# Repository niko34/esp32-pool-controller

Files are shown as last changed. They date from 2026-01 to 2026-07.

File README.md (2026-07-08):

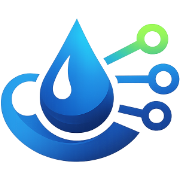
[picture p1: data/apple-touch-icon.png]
<h1> ESP32 Pool Controller</h1>

Disclaimer : projet en cours de construction.

Contrôleur automatique de piscine basé sur ESP32 :
- mesure : température, pH, ORP
- pilotage : pompe de filtration, éclairage
- correction avec pompes doseuses : pH et ORP
- interfaces : application web locale, MQTT, API

## 🎯 Fonctionnalités

### Mesures et Contrôle
- **pH** : Mesure via module numérique Atlas Scientific **EZO pH** (I²C). La température de l'eau est transmise au module pour la compensation de température de la mesure.
- **ORP (Redox)** : Mesure via module numérique Atlas Scientific **EZO ORP** (I²C)
- **Température** : Deux sondes Dallas **DS18B20** (eau + circuit/boîtier), identification automatique des rôles sur le bus OneWire
- **Historique** : Historique des mesures
- **Mode d'installation** : Décrit le câblage réel du contrôleur et garantit qu'aucun produit n'est injecté sans circulation d'eau — *PoolController pilote la filtration* (sortie 12 V), *Alimenté par le circuit de filtration*, ou *Filtration externe signalée* (une domotique tierce signale l'état via HTTP/MQTT ; dosage suspendu sans signal récent)
- **Filtration** : Programmation automatique en fonction de la température de l'eau, programmation horaire, manuel
- **Eclairage** : Programmation horaire, manuel
- **Régulation automatique de pH et ORP** : Injection de produit de correction (pH-, chlore liquide) par **régulation proportionnelle temporisée (P)** avec pause de mélange et contrôle de débit PWM. Les mesures sont **lissées** (médiane + EMA) avant d'alimenter la régulation. *(pH+ : option de configuration présente mais non gérée actuellement.)*
- **Consommation de produits** : Estimation de la consommation de produit
- **Application Web locale** : Configuration et visualisation temps réel. Accessible sur le réseau Wifi configuré (`http://poolcontroller.local`) ou un réseau Wifi de en mode point d'accès (`http://192.168.4.1`). Aucune dépendance au Cloud. [Voir les screenshots](screenshots/)
- **API** : Toutes les fonctionnalités sont exposées avec une API
- **MQTT** : Exposition des données sur MQTT. Auto-discovery HomeAssistant.
- **Mise à jour OTA** : Mise à jour firmware via interface web

### Sécurité
- ⚠️ **Limites journalières** : Protection contre le surdosage
- ⚠️ **Limites horaires** : Temps maximum d'injection par heure configurable
- ⚠️ **Watchdog** : Redémarrage automatique en cas de blocage du système (30s)
- ⚠️ **Alertes MQTT** : Notifications en cas d'anomalie

## 📋 Matériel Requis

### PCB

Les fichiers pour la partie électronique sont disponibles dans le dossier [`hardware/`](hardware/) :

- [Schéma électronique](screenshots/Schema.png)
- [PCB](screenshots/PCB.png)
- [Fichiers Gerber](hardware/Gerber.zip)
- [BOM](hardware/BOM.csv)

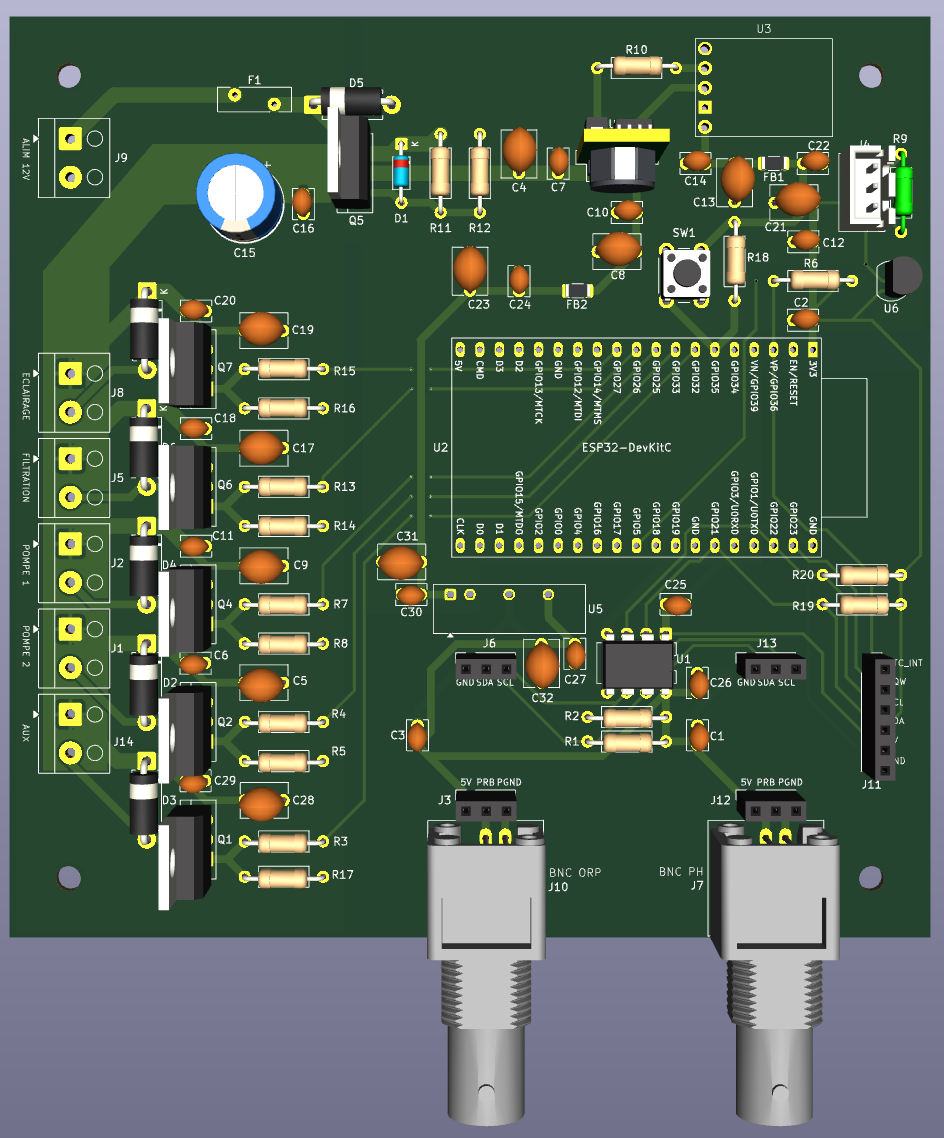
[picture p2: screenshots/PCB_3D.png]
PCB


### Boîtier

Les fichiers STL pour l’impression 3D du boîtier sont disponibles dans le dossier [`hardware/`](hardware/) :

- [`esp32-pool-controller v3-Boitier.stl`](hardware/esp32-pool-controller%20v3-Boitier.stl) — Corps du boîtier
- [`esp32-pool-controller v3-Couvercle.stl`](hardware/esp32-pool-controller%20v3-Couvercle.stl) — Couvercle

## 🚀 Installation

### PlatformIO (Recommandé)

1. **Cloner le projet**
   ```bash
   git clone https://github.com/niko34/esp32-pool-controller.git
   cd esp32-pool-controller
   ```

2. **Ouvrir avec VS Code + PlatformIO**
   ```bash
   code .
   ```

3. **Compiler et déployer**

   **Via USB** (obligatoire pour la première installation — bootloader et table de partitions) :
   ```bash
   ./deploy.sh all       # Compile et upload firmware + filesystem
   ./deploy.sh firmware  # Firmware uniquement
   ./deploy.sh fs        # Filesystem uniquement
   ```

   **Via WiFi OTA** (mises à jour suivantes, une fois la première installation USB effectuée) :
   ```bash
   ./deploy.sh ota-all       # Compile et envoie firmware + filesystem
   ./deploy.sh ota-firmware  # Firmware uniquement
   ./deploy.sh ota-fs        # Filesystem uniquement
   ```

   Voir [UPDATE_GUIDE.md](docs/UPDATE_GUIDE.md) pour plus de détails sur les méthodes de mise à jour.

4. **Moniteur série**
   ```bash
   pio device monitor -b 115200
   ```

### Première connexion et accès à l'interface Web

1. **Première connexion**
   - Au démarrage, l'ESP32 crée un point d'accès WiFi `PoolControllerAP`
   - Le mot de passe WiFi AP est **unique par appareil**, généré aléatoirement au premier boot et stocké en NVS
   - Il s'affiche en clair dans le moniteur série **tant que le wizard de configuration n'est pas complété** :
     ```
     [INFO] AP démarré: PoolControllerAP
     [INFO] AP Password: XXXXXXXX
     [INFO] IP AP: 192.168.4.1
     ```
   - Ouvrir le moniteur série **avant** d'alimenter l'appareil : `pio device monitor -b 115200`
   - Coller le mot de passe sur une étiquette sur le boîtier
   - Se connecter au réseau `PoolControllerAP` avec ce mot de passe et accéder à l'assistant de configuration http://192.168.4.1

   > **Après le wizard complété**, si l'AP redémarre (ex : perte WiFi), le mot de passe n'est plus affiché en clair dans les logs pour des raisons de sécurité. Utiliser l'étiquette ou l'API :
   > ```
   > GET http://poolcontroller.local/auth/ap-password
   > ```

   > **Forcer la génération d'un nouveau mot de passe AP** (ex : fabrication d'un nouvel appareil, remplacement d'étiquette) : utiliser l'option `factory` qui efface toute la flash avant de flasher.
   > ```bash
   > ./deploy.sh factory
   > pio device monitor -b 115200   # ouvrir avant d'alimenter l'appareil
   > ```
   > ⚠️ Efface **toute** la flash (firmware, filesystem, NVS, historique). À n'utiliser que sur un appareil qu'on réinitialise complètement.

2. **Accès interface web**
   - `http://poolcontroller.local` si réseau wifi configuré, sinon se connecter au réseau AP PoolControllerAP et utiliser l'adresse http://192.168.4.1
   - Onglets disponibles:
     - **Tableau de bord** : Visualisation temps réel pH/ORP/Température
     - **Filtration** : Contrôle et programmation de la pompe de filtration
     - **Éclairage** : Contrôle et programmation de l'éclairage
     - **Température** : Historique et calibration de la sonde de température
     - **pH** : Mesure, historique, calibration et réglages dosage pH
     - **ORP** : Mesure, historique, calibration et réglages dosage chlore
     - **Produits** : Suivi de la consommation des produits chimiques
     - **Paramètres** : WiFi, MQTT, heure, sécurité, régulation, système

### Calibration Capteurs

#### Calibration pH (Atlas Scientific EZO pH)

La calibration est gérée **en interne par le module EZO** (commandes I²C `Cal,...`), mémorisée dans le module lui-même — il n'y a ni offset/pente stockés côté ESP32, ni EEPROM, ni librairie analogique. Elle se déclenche depuis l'interface web, onglet **pH** → carte **Calibration** (deux sous-blocs indépendants). Le module EZO pH accepte les points **milieu (pH 7.0)**, **bas (pH 4.0)** et, optionnellement, **haut**. La régulation automatique du pH est **inhibée tant que les 2 points (mid + low) ne sont pas calibrés**.

**Calibration via l'interface web** :
1. Aller dans l'onglet **pH** → carte **Calibration**
2. Rincer la sonde à l'eau distillée, la plonger dans la solution tampon **pH 7.00**, attendre stabilisation (~1 min)
3. Cliquer sur **« Calibrer le point 7.0 »** (sous-bloc *Point milieu*)
4. Rincer la sonde, la plonger dans la solution **pH 4.00**, attendre stabilisation
5. Cliquer sur **« Calibrer le point 4.0 »** (sous-bloc *Point bas*)

> **Compensation de température** : la température de l'eau mesurée par la DS18B20 est transmise au module EZO pour compenser la mesure de pH.

Détails du workflow et des cas d'erreur : voir [docs/features/page-ph.md](docs/features/page-ph.md).

#### Calibration ORP (Atlas Scientific EZO ORP)

La calibration ORP est une commande **interne au module EZO** (`Cal,<référence>`, un seul point), déclenchée depuis l'interface web, onglet **ORP** → carte **Calibration**. Comme pour le pH, aucun offset/date n'est calculé ni stocké côté ESP32. La régulation automatique de l'ORP est **inhibée tant que le module n'est pas calibré**.

**Calibration via l'interface web** :
1. Aller dans l'onglet **ORP** → carte **Calibration**
2. Rincer la sonde à l'eau déminéralisée, la plonger dans la solution de référence ORP
3. Saisir la valeur de référence de la solution dans le champ (ex : 470 mV ; plage acceptée 0–1000 mV)
4. Attendre stabilisation (~1 min), puis cliquer sur **« Calibrer »**

Détails du workflow et des cas d'erreur : voir [docs/features/page-orp.md](docs/features/page-orp.md).

### Tuning de la régulation (Avancé)

La régulation est une **proportionnelle temporisée (P)** : seul le gain **Kp** module la vitesse, **Ki = 0** et **Kd = 0** sont impératifs (pas d'intégrale ni de dérivée). La valeur d'entrée de la régulation est la mesure **lissée** (médiane + EMA) ; le dosage est **bloqué tant que le filtre de mesure n'est pas amorcé/prêt**. Voir [applyRegulationSpeed()](src/pump_controller.cpp) et [ADR-0016](docs/adr/0016-regulation-p-temporisee-vs-pid.md).

**Gain Kp par vitesse** (sélectionnable dans Paramètres → Régulation) :

| Vitesse | Kp pH | Kp ORP |
|---|---|---|
| Lente | 4.0 | 0.15 |
| Normale | 8.0 | 0.30 |
| Rapide  | 12.0  | 0.50 |

> **Ki = 0 / Kd = 0** quelle que soit la vitesse (P temporisée pure). `integralMax` (50.0) est conservé pour une éventuelle réactivation future mais reste **inerte** tant que Ki = 0.

**Protection anti-cycling** (prolonge durée de vie des pompes) :
- Injection minimum : 30 secondes par cycle
- Pause de mélange : **15 min** (pH) / **20 min** (ORP) après chaque injection (`kPhMixingDelayMs` / `kOrpMixingDelayMs`)
- Seuils de démarrage : pH ±0.05 / ORP ±15 mV
- Seuils d'arrêt : pH ±0.01 / ORP ±2 mV
- Maximum : 20 cycles par jour

## 🏠 Intégration Home Assistant

### Auto-Discovery

Le contrôleur publie automatiquement sa configuration MQTT pour Home Assistant :

| Type | Entité | Description |
|---|---|---|
| Sensor | Température | Température de l'eau (°C) |
| Sensor | pH | Valeur pH |
| Sensor | ORP | Valeur ORP (mV) |
| Binary Sensor | Filtration active | État de la pompe de filtration (ON/OFF) |
| Binary Sensor | Dosage pH actif | Pompe doseuse pH en cours d'injection |
| Binary Sensor | Dosage chlore actif | Pompe doseuse ORP en cours d'injection |
| Binary Sensor | Limite journalière pH | Limite de dosage pH atteinte |
| Binary Sensor | Limite journalière chlore | Limite de dosage ORP atteinte |
| Binary Sensor | Statut contrôleur | Disponibilité du contrôleur (online/offline) |
| Select | Mode filtration | Sélection du mode (auto / manual / force / off) |
| Switch | Filtration ON/OFF | Forçage marche/arrêt de la filtration |
| Switch | Éclairage ON/OFF | Contrôle de l'éclairage |
| Number | Consigne pH | Valeur cible pH (6.0 – 8.5, pas 0.1) |
| Number | Consigne ORP | Valeur cible ORP en mV (400 – 900, pas 10) |

### Exemple Automation

```yaml
automation:
  - alias: "Alerte pH Anormal"
    trigger:
      - platform: numeric_state
        entity_id: sensor.piscine_ph
        above: 7.6
        for: "00:15:00"
    action:
      - service: notify.mobile_app
        data:
          title: "Piscine - pH Élevé"
          message: "pH: {{ states('sensor.piscine_ph') }}"

  - alias: "Notification Limite Injection"
    trigger:
      - platform: mqtt
        topic: "pool/sensors/alerts"
    condition:
      - condition: template
        value_template: "{{ 'limit' in trigger.payload_json.type }}"
    action:
      - service: notify.mobile_app
        data:
          title: "Piscine - Alerte Sécurité"
          message: "{{ trigger.payload_json.message }}"
```

## 🔐 Sécurité

### Factory Reset (bouton physique)

En cas d'oubli du mot de passe ou de nécessité de réinitialisation complète, utiliser le bouton factory reset situé à côté de l'ESP32 sur la carte électronique.

**Procédure de réinitialisation:**

Le factory reset se déclenche pendant le fonctionnement normal de l'ESP32 (pas besoin de couper l'alimentation) :

1. **Appuyer et maintenir** le bouton factory reset
   - Le log série affiche : `Bouton reset enfoncé - maintenir 10s pour factory reset`
2. **Maintenir 10 secondes**
   - Relâcher avant 10s annule la réinitialisation (log : `factory reset annulé`)
3. L'ESP32 redémarre automatiquement
3. Suivre les instructions données plus haut dans la partie "1ère connexion"

**Ce qui est réinitialisé (partition NVS effacée entièrement) :**
- ✅ Mot de passe admin (retour à `admin`)
- ✅ Token API régénéré
- ✅ Credentials WiFi supprimés (retour en mode AP)
- ✅ Configuration MQTT effacée
- ✅ Calibrations des sondes (pH, ORP) effacées

**Ce qui N'EST PAS effacé :**
- ✅ **Mot de passe WiFi AP** — préservé intentionnellement (l'étiquette sur le boîtier reste valide)
- ✅ Fichiers JSON sur LittleFS (consignes, limites, config) — préservés
- ✅ Historique des mesures (partition séparée) — préservé

## 📈 Changelog

Voir [CHANGELOG.md](CHANGELOG.md) pour l'historique complet des versions.

## 📁 Fichiers et Scripts

### Scripts de Build et Déploiement

- **`deploy.sh`** - Script de déploiement principal
  - `./deploy.sh all` - Compile et upload USB firmware + filesystem (NVS préservée)
  - `./deploy.sh factory` - Efface toute la flash, compile et upload firmware + filesystem (génère un nouveau mot de passe AP)
  - `./deploy.sh firmware` - Compile et upload USB firmware uniquement
  - `./deploy.sh fs` - Compile et upload USB filesystem uniquement
  - `./deploy.sh ota-all` - Compile et envoie OTA (WiFi) firmware + filesystem
  - `./deploy.sh ota-firmware` - Compile et envoie OTA firmware uniquement
  - `./deploy.sh ota-fs` - Compile et envoie OTA filesystem uniquement

- **`build_fs.sh`** - Construction du filesystem LittleFS
  - Minifie automatiquement HTML/CSS/JS
  - Construit LittleFS avec la bonne taille (832 KB — 851 968 octets)
  - Utilise `data-build/` comme source (généré par minify.js)

- **`minify.js`** - Minification des fichiers web
  - Utilise des outils professionnels standards de l'industrie:
    - **html-minifier-terser** - Minification HTML
    - **Terser** - Minification JavaScript
    - **CleanCSS** - Minification CSS
  - Source: `data/` → Destination: `data-build/`
  - Exécuté automatiquement par `build_fs.sh`

### Configuration

- **`platformio.ini`** - Configuration PlatformIO
  - Définit les dépendances, ports, partitions
  - Port série: `/dev/cu.usbserial-0001` (à adapter)

- **`partitions.csv`** - Table de partitions ESP32 4MB (layout v2, [ADR-0015](docs/adr/0015-partition-app-1.5mb.md))
  - 2× slots OTA app0/app1 (1.5 MB / 1536 KB chacun)
  - LittleFS/spiffs (832 KB) pour l'interface web
  - History (64 KB) partition séparée préservée lors des mises à jour

### Documentation

- **[`docs/API.md`](docs/API.md)** - Documentation de l'API REST
- **[`docs/MQTT.md`](docs/MQTT.md)** - Documentation des topics MQTT
- **[`docs/BUILD.md`](docs/BUILD.md)** - Instructions de compilation détaillées
- **[`docs/UPDATE_GUIDE.md`](docs/UPDATE_GUIDE.md)** - Guide de mise à jour (USB, WiFi OTA, GitHub)
- **`README.md`** - Ce fichier

### Dossiers

- **`src/`** - Code source C++ du firmware
- **`data/`** - Fichiers web sources (HTML/CSS/JS) — versionnés
- **`data-build/`** - Fichiers web minifiés — générés automatiquement (ignoré par git)
- **`hardware/`** - Fichiers Gerber, BOM et STL du boîtier
- **`kicad/`** - Schémas électroniques KiCad
- **`docs/`** - Documentation technique complémentaire
- **`screenshots/`** - Captures d'écran de l'interface
- **`tools/`** - Scripts utilitaires (ex: test UART)
- **`logo/`** - Fichiers logo du projet

## 📄 Licence

MIT License - Voir fichier LICENSE

## ⚠️ Avertissement

Ce projet est fourni "tel quel" sans garantie. L'utilisation de produits chimiques et d'équipements électriques près de l'eau présente des risques. L'utilisateur est seul responsable de:
- La conformité aux réglementations locales
- La sécurité de l'installation
- Le bon dosage des produits chimiques
- La surveillance du système

**En cas de doute, consulter un professionnel.**

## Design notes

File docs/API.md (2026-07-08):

# API Documentation - ESP32 Pool Controller

## Authentification

Tous les endpoints nécessitent une authentification sauf ceux marqués **public**.

### Méthodes d'Authentification

#### HTTP Basic Auth

```bash
curl -u admin:monmotdepasse http://poolcontroller.local/get-config
```

#### Token API (header)

```bash
curl -H "X-Auth-Token: abc123def456..." http://poolcontroller.local/get-config
```

Le token API est généré automatiquement au premier démarrage. Il est visible dans **Paramètres → Système → Token API** et peut être régénéré via `/auth/regenerate-token`.

### Niveaux de protection

| Niveau | Description |
|---|---|
| Public | Accessible sans authentification |
| WRITE  | Authentification requise |
| CRITICAL | Authentification requise — opérations sensibles |

### Politique d'origine — pas de CORS

Le contrôleur applique une **politique même-origine stricte** ([ADR-0023](adr/0023-politique-cors-retrait.md), v2.11.2) : aucun en-tête `Access-Control-Allow-*` n'est émis, aucun preflight `OPTIONS` n'est traité. L'UI est servie par l'ESP32 lui-même — un navigateur ne peut pas appeler cette API depuis une page hébergée sur une autre origine. Les clients non-navigateur (`curl`, scripts, intégrations serveur) ne sont pas concernés. Pour une intégration cross-origin navigateur, passer par un reverse proxy.

Détails techniques :
- La comparaison du token API est à **temps constant** (HTTP et WebSocket) — voir [docs/subsystems/auth.md](subsystems/auth.md).
- Le token n'est accepté **que** via le header `X-Auth-Token` (jamais en query param `?token=...`).

### Recommandations de sécurité

- Utiliser un réseau WiFi sécurisé
- Ne pas exposer l'ESP32 directement sur Internet
- Changer le mot de passe admin par défaut
- Utiliser le token API plutôt que le mot de passe dans les scripts automatisés

---

## Codes d'erreur

| Code | Description |
|---|---|
| 200  | Succès |
| 400  | Requête invalide (paramètre manquant ou JSON invalide) |
| 401  | Authentification requise ou mot de passe incorrect |
| 403  | Accès refusé (ex: wizard déjà complété) |
| 404  | Endpoint introuvable |
| 409  | Conflit d'état — typiquement injection manuelle refusée car filtration arrêtée (sécurité chimique). Voir [`POST /ph/inject/start`](#post-phinjectstart--write). |
| 429  | Trop de requêtes (rate limiting) |
| 500  | Erreur serveur |

---

## Authentification et Wizard

### GET /auth/status — public

Retourne l'état d'authentification du système.

```bash
curl http://poolcontroller.local/auth/status
```

```json
{
  "firstBoot": false,
  "authEnabled": true,
  "forceWifiConfig": false
}
```

---

### POST /auth/login — public

Authentifie l'utilisateur et retourne le token API.

```bash
curl -X POST -H "Content-Type: application/json" \
  -d '{"username":"admin","password":"monmotdepasse"}' \
  http://poolcontroller.local/auth/login
```

```json
{
  "success": true,
  "token": "abc123def456...",
  "username": "admin"
}
```

> ⚠️ Bloqué si `firstBoot=true` — le mot de passe doit d'abord être changé via `/auth/change-password`.

---

### POST /auth/change-password — public (premier démarrage) / WRITE (ensuite)

Change le mot de passe admin. Accessible sans authentification lors du premier démarrage.

```bash
curl -X POST -H "Content-Type: application/json" \
  -d '{"currentPassword":"admin","newPassword":"nouveaumotdepasse"}' \
  http://poolcontroller.local/auth/change-password
```

```json
{
  "success": true,
  "token": "abc123def456...",
  "message": "Password changed successfully"
}
```

Règles : minimum 8 caractères, différent du mot de passe actuel.

---

### POST /auth/complete-wizard — public (premier démarrage uniquement)

Marque le wizard de configuration initiale comme complété.

```bash
curl -X POST http://poolcontroller.local/auth/complete-wizard
```

---

### GET /auth/token — CRITICAL

Retourne le token API courant.

```bash
curl -u admin:monmotdepasse http://poolcontroller.local/auth/token
```

```json
{ "token": "abc123def456..." }
```

---

### POST /auth/regenerate-token — CRITICAL

Régénère un nouveau token API (invalide l'ancien).

```bash
curl -u admin:monmotdepasse -X POST http://poolcontroller.local/auth/regenerate-token
```

```json
{
  "success": true,
  "token": "nouveautoken...",
  "message": "API token regenerated"
}
```

---

### GET /auth/ap-password — CRITICAL

Retourne le mot de passe WiFi du point d'accès `PoolControllerAP`. Utile si l'étiquette collée sur le boîtier est illisible ou perdue.

```bash
curl -u admin:monmotdepasse http://poolcontroller.local/auth/ap-password
```

```json
{
  "ap_ssid": "PoolControllerAP",
  "ap_password": "XXXXXXXX"
}
```

> Le mot de passe AP est généré aléatoirement au premier boot et ne change pas lors des mises à jour OTA ni des factory resets (bouton physique). Pour en générer un nouveau, utiliser `./deploy.sh factory`.

---

## Données et Historique

### GET /data — WRITE

Retourne les valeurs actuelles des capteurs.

```bash
curl -u admin:monmotdepasse http://poolcontroller.local/data
```

```json
{
  "orp": 720,
  "ph": 7.234,
  "temperature": 24.5,
  "temperature_circuit": 28.1,
  "phCalPoints": 2,
  "orpCalPoints": 1,
  "phRaw": 7.241,
  "phMedian": 7.236,
  "phFiltered": 7.234,
  "phFilterReady": true,
  "phFilterUnstable": false,
  "phRejectedCount": 0,
  "orpRaw": 722,
  "orpMedian": 720,
  "orpFiltered": 720,
  "orpFilterReady": true,
  "orpFilterUnstable": false,
  "orpRejectedCount": 0,
  "filtration_running": true,
  "ph_dosing": false,
  "orp_dosing": false,
  "ph_daily_ml": 45.2,
  "orp_daily_ml": 120.5,
  "ph_limit_reached": false,
  "orp_limit_reached": false,
  "ph_tracking_enabled": true,
  "ph_remaining_ml": 1500,
  "ph_alert_threshold_ml": 500,
  "orp_tracking_enabled": true,
  "orp_remaining_ml": 3200,
  "orp_alert_threshold_ml": 1000
}
```

> **feature-021** : `ph` est désormais publié avec **3 décimales** (vs 1 décimale en v1.x). Champs `phCalPoints` (`-1..3`) et `orpCalPoints` (`-1..1`) ajoutés. Champs **supprimés** de la réponse `/data` : `orp_raw`, `ph_raw`, `ph_voltage_mv`, `temperature_raw` (la notion de « valeur brute » n'a pas de sens côté Atlas EZO — la valeur est déjà calibrée par le module). Voir [ADR-0014](adr/0014-migration-atlas-ezo.md).
>
> **feature-025** : `ph` / `orp` correspondent désormais à la valeur **filtrée** (médiane + EMA), avec fallback sur le brut tant que le filtre n'est pas amorcé. Champs `phRaw/phMedian/phFiltered/phFilterReady/phFilterUnstable/phRejectedCount` (+ équivalents `orp*`) ajoutés. Les champs flottants valent `null` si la mesure est indisponible (stale / non amorcé). Mêmes champs côté WS. Voir [`docs/subsystems/sensors.md`](subsystems/sensors.md#filtrage-des-mesures-phorp--feature-025).

---

### GET /get-history — WRITE

Retourne l'historique des mesures.

```bash
curl -u admin:monmotdepasse "http://poolcontroller.local/get-history?range=24h"
```

Paramètre `range` : `24h` (défaut), `3d`, `7d`, `30d`, `all`.

Paramètre optionnel `?since=TIMESTAMP` pour récupération incrémentale.

---

### POST /history/clear — CRITICAL

Efface tout l'historique des mesures.

```bash
curl -u admin:monmotdepasse -X POST http://poolcontroller.local/history/clear
```

---

### POST /history/import — WRITE

Importe un lot de points d'historique.

```bash
curl -u admin:monmotdepasse -X POST -H "Content-Type: application/json" \
  -d '[{"timestamp":1700000000,"ph":7.2,"orp":720,"temperature":24.5}]' \
  http://poolcontroller.local/history/import
```

---

### GET /get-logs — WRITE

Retourne les 200 derniers logs système. Paramètre optionnel `?since=TIMESTAMP` pour récupération incrémentale (ne retourne que les entrées postérieures à ce timestamp).

```bash
curl -u admin:monmotdepasse http://poolcontroller.local/get-logs
curl -u admin:monmotdepasse "http://poolcontroller.local/get-logs?since=14400000"
```

```json
{
  "logs": [
    { "timestamp": 14400000, "level": "INFO", "message": "Capteurs initialisés" },
    { "timestamp": 14405000, "level": "WARNING", "message": "pH hors limites: 7.8" }
  ]
}
```

> `timestamp` est exprimé en millisecondes depuis le démarrage de l'ESP32 (`millis()`).

---

### GET /download-logs — WRITE

Télécharge les logs système sous forme de fichier texte (`pool_logs.txt`).

```bash
curl -u admin:monmotdepasse http://poolcontroller.local/download-logs -o pool_logs.txt
```

```
# Pool Controller — Journal système
# Exporté le boot+3600s | Entrées: 42
# Format: [+Xs] NIVEAU : message

[+01:00:00] INFO : Démarrage dosage pH: pH=7.85 cible=7.20 erreur=+0.65
[+01:00:45] INFO : Arrêt dosage pH: durée=45s vol≈3.5mL total jour=3.5/300mL — pause 30min
[+01:31:00] INFO : Démarrage dosage pH: pH=7.78 cible=7.20 erreur=+0.58
```

> Les logs enrichis incluent les événements de dosage (démarrage, arrêt, paramètres) ainsi que les alertes de limites horaires/journalières.

---

### DELETE /logs — WRITE

Efface intégralement les logs côté ESP32 : buffer RAM circulaire, tampon de flush en attente, fichier persistant `/system.log` et son éventuel `.tmp` de rotation.

```bash
curl -u admin:monmotdepasse -X DELETE http://poolcontroller.local/logs
```

```json
{ "success": true }
```

Une entrée `INFO : Logs effacés (RAM + fichier persistant)` est écrite immédiatement après l'effacement pour tracer l'action.

> ⚠️ Action irréversible. Pour ne vider que la vue navigateur sans toucher au firmware, utiliser le bouton « Effacer (écran) » côté UI.

---

## Configuration

### GET /get-config — WRITE

Retourne la configuration complète du système.

```bash
curl -u admin:monmotdepasse http://poolcontroller.local/get-config
```

```json
{
  "server": "mqtt.example.com",
  "port": 1883,
  "topic": "pool/controller",
  "enabled": true,
  "install_mode": "managed",
  "regulation_speed": "normal",
  "stabilization_delay_min": 5,
  "ph_correction_type": "ph_minus",
  "ph_target": 7.2,
  "orp_target": 700,
  "ph_regulation_enabled": true,
  "ph_pump": 1,
  "pump1_max_duty_pct": 50,
  "orp_regulation_enabled": true,
  "orp_pump": 2,
  "pump2_max_duty_pct": 50,
  "pump_max_flow_ml_per_min": 90,
  "ph_limit_minutes": 5,
  "orp_limit_minutes": 10,
  "time_use_ntp": true,
  "ntp_server": "pool.ntp.org",
  "timezone_id": "europe_paris",
  "filtration_mode": "auto",
  "filtration_start": "08:00",
  "filtration_end": "20:00",
  "lighting_feature_enabled": true,
  "lighting_enabled": false,
  "lighting_schedule_enabled": true,
  "lighting_start": "20:00",
  "lighting_end": "23:00",
  "temperature_enabled": true,
  "wifi_ssid": "MonWiFi",
  "wifi_ip": "192.168.1.100",
  "max_ph_ml_per_day": 1000,
  "max_chlorine_ml_per_day": 1000,
  "time_current": "2026-03-28T14:30:45",
  "sensor_logs_enabled": false,
  "debug_logs_enabled": false,
  "boost_active": false,
  "boost_until": 0
}
```

---

Champs notables de la réponse :

| Champ | Type | Description |
|---|---|---|
| `install_mode` | string | **Mode d'installation** (feature-056, v2.19.0). `"managed"` (PoolController pilote la filtration : relais GPIO 26 piloté, programmation active, eau présente = filtration commandée ON), `"powered"` (contrôleur alimenté par le circuit de filtration : relais inerte, programmation masquée, eau présumée présente en permanence — ex-`continu`), `"external"` (filtration tierce signalée : relais inerte, eau présente seulement si dernier signal ON reçu < 180 s, sinon dosage suspendu). Remplace `regulation_mode` **et** `filtration_enabled`. Voir [ADR-0026](adr/0026-mode-installation.md). |
| `regulation_speed` | string | `"slow"` / `"normal"` / `"fast"` — préréglages PID |
| `stabilization_delay_min` | integer | Délai de stabilisation capteurs après démarrage filtration (0–60 min) |
| `ph_limit_minutes` | integer | Durée max d'injection pH par fenêtre glissante d'1 h (minutes, 1–60) |
| `orp_limit_minutes` | integer | Durée max d'injection ORP par fenêtre glissante d'1 h (minutes, 1–60) |
| `pump1_max_duty_pct` | integer | Puissance maximale pompe 1 en régulation (0–100 %) |
| `pump2_max_duty_pct` | integer | Puissance maximale pompe 2 en régulation (0–100 %) |
| `pump_max_flow_ml_per_min` | float | Débit nominal des pompes à 100 % de puissance (mL/min) |
| `ph_regulation_mode` | string | Mode de régulation pH : `"automatic"` (PID vers ph_target), `"scheduled"` (volume quotidien réparti sur 24 h), `"manual"` (aucune régulation automatique) |
| `ph_daily_target_ml` | integer | Volume quotidien cible en mL pour le mode Programmée pH (0 = désactivé, borné par `max_ph_ml_per_day`) |
| `ph_enabled` | boolean | Miroir dérivé de `ph_regulation_mode` : `true` si mode ≠ `"manual"`. Maintenu pour compatibilité MQTT / HA. |
| `orp_regulation_mode` | string | Mode de régulation ORP : `"automatic"` (PID vers orp_target), `"scheduled"` (volume quotidien de chlore, aveugle au capteur), `"manual"` (aucune régulation automatique) |
| `orp_daily_target_ml` | integer | Volume quotidien cible en mL pour le mode Programmée ORP (0 = désactivé, borné par `max_orp_ml_per_day`) |
| `orp_enabled` | boolean | Miroir dérivé de `orp_regulation_mode` : `true` si mode ≠ `"manual"`. Maintenu pour compatibilité MQTT / HA. |
| `max_orp_ml_per_day` | float | Limite journalière ORP configurée (mL) — alias de `max_chlorine_ml_per_day` |
| `orp_cal_valid` | boolean | `true` si une calibration ORP a déjà été enregistrée (date non vide) |
| `sensor_logs_enabled` | boolean | Verbosité des logs capteurs (default `false`). Modifiable via Paramètres → Avancé → « Log des sondes ». |
| `debug_logs_enabled` | boolean | Active la production des logs de niveau `DEBUG` côté firmware (default `false`). Quand `false`, `Logger::debug()` court-circuite immédiatement (early return). Les niveaux `INFO`/`WARN`/`ERROR`/`CRITICAL` ne sont pas affectés. Modifiable via Paramètres → Avancé → « Logs DEBUG activés ». Persisté en NVS sous la clé `debug_logs`. Effet immédiat, pas de redémarrage requis. |
| `boost_active` | boolean | Mode Boost actif (feature-053, v2.18.0). `true` tant que la surchloration temporaire du jour est en cours. Piloté par `POST /boost/start` \| `/boost/stop` (jamais par `/save-config`). Persisté en NVS (survit à un reboot dans la journée), expire automatiquement au prochain minuit local. Voir [ADR-0025](adr/0025-mode-boost.md). |
| `boost_until` | integer (epoch) | Instant d'expiration du Boost (epoch UNIX, prochain minuit local). `0` si le Boost est inactif. Permet à l'UI d'afficher l'heure de fin. |

**`POST /save-config` — champs pH spécifiques :**

| Champ | Type | Validation |
|---|---|---|
| `ph_regulation_mode` | string | Valeurs acceptées : `"automatic"`, `"scheduled"`, `"manual"`. Toute autre valeur est ignorée. Met à jour `ph_enabled` automatiquement. |
| `ph_daily_target_ml` | integer | Doit être ≥ 0 et ≤ `max_ph_ml_per_day` (si configuré). Retourne HTTP 400 si la limite est dépassée. |

**`POST /save-config` — champs ORP spécifiques :**

| Champ | Type | Validation |
|---|---|---|
| `orp_regulation_mode` | string | Valeurs acceptées : `"automatic"`, `"scheduled"`, `"manual"`. Toute autre valeur est ignorée. Met à jour `orp_enabled` automatiquement. |
| `orp_daily_target_ml` | integer | Doit être ≥ 0 et ≤ `max_orp_ml_per_day` (si configuré). Retourne HTTP 400 si la limite est dépassée. |

**`POST /save-config` — mode d'installation :**

| Champ | Type | Validation |
|---|---|---|
| `install_mode` | string | Valeurs acceptées : `"managed"`, `"powered"`, `"external"`. Toute autre valeur est ignorée (mode courant conservé). |

> ⚠️ **Retirés en v2.19.0 (feature-056)** : les champs `regulation_mode` et `filtration_enabled` **n'existent plus** dans `/get-config` ni `/save-config`. Ils sont fusionnés dans `install_mode` (voir [ADR-0026](adr/0026-mode-installation.md)). La migration NVS est automatique — voir [UPDATE_GUIDE.md](UPDATE_GUIDE.md).

---

### POST /save-config — CRITICAL

Sauvegarde la configuration complète. Corps JSON identique à la réponse de `/get-config`.

```bash
curl -u admin:monmotdepasse -X POST -H "Content-Type: application/json" \
  -d '{"ph_target":7.2,"orp_target":700}' \
  http://poolcontroller.local/save-config
```

---

### GET /get-system-info — WRITE

Retourne les informations système de l'ESP32.

```bash
curl -u admin:monmotdepasse http://poolcontroller.local/get-system-info
```

```json
{
  "firmware_version": "1.0.3",
  "build_date": "Mar 28 2026",
  "chip_model": "ESP32-D0WDQ6",
  "cpu_freq_mhz": 240,
  "free_heap": 123456,
  "heap_size": 327680,
  "flash_size": 4194304,
  "ota_partition": "app0",
  "ota_partition_size": 1703936,
  "sketch_size": 1427753,
  "fs_total_bytes": 1507328,
  "fs_used_bytes": 245760,
  "wifi_ssid": "MonWiFi",
  "wifi_rssi": -45,
  "wifi_ip": "192.168.1.100",
  "wifi_mac": "AA:BB:CC:DD:EE:FF",
  "uptime_seconds": 86400,
  "uptime_days": 1,
  "uptime_hours": 0,
  "uptime_minutes": 0
}
```

> `sketch_size` (octets, `ESP.getSketchSize()`) et `ota_partition_size` (octets, taille de la partition app active) permettent de calculer l'occupation flash du firmware — affichée sur la ligne « Firmware (flash) » de la carte Infos système (v2.5.2). `sketch_size` ajouté en v2.5.2 (feature-047).

---

### GET /time-now — WRITE

Retourne l'heure système courante.

```bash
curl -u admin:monmotdepasse http://poolcontroller.local/time-now
```

```json
{
  "time": "2026-03-28T14:30:45",
  "time_use_ntp": true,
  "timezone_id": "europe_paris"
}
```

---

## WiFi

### GET /wifi/status — public

Retourne l'état de la connexion WiFi.

```bash
curl http://poolcontroller.local/wifi/status
```

```json
{
  "mode": "STA",
  "connected": true,
  "ssid": "MonWiFi",
  "ap_ssid": "PoolControllerAP",
  "ap_ip": "192.168.4.1"
}
```

---

### GET /wifi/scan — public (mode AP) / WRITE (mode STA)

Scanne les réseaux WiFi disponibles.

```bash
curl http://poolcontroller.local/wifi/scan
```

```json
{
  "networks": [
    { "ssid": "MonWiFi", "rssi": -45, "channel": 6, "secure": true }
  ]
}
```

---

### POST /wifi/connect — public (mode AP) / WRITE (mode STA)

Se connecte à un réseau WiFi.

```bash
curl -X POST -H "Content-Type: application/json" \
  -d '{"ssid":"MonWiFi","password":"wifipassword"}' \
  http://poolcontroller.local/wifi/connect
```

```json
{
  "accepted": true,
  "message": "WiFi connection request accepted, connecting asynchronously"
}
```

---

### POST /wifi/disconnect — WRITE

Déconnecte du WiFi et efface les credentials.

```bash
curl -u admin:monmotdepasse -X POST http://poolcontroller.local/wifi/disconnect
```

---

### POST /wifi/ap/disable — CRITICAL

Désactive le mode point d'accès.

```bash
curl -u admin:monmotdepasse -X POST http://poolcontroller.local/wifi/ap/disable
```

---

## WebSocket temps réel

### WS /ws — WRITE

Flux temps réel basse latence. L'ESP32 pousse un message JSON à chaque changement d'état significatif (mesures capteurs, dosage, configuration).

**Connexion**

```js
const ws = new WebSocket('ws://poolcontroller.local/ws');
```

**Message d'état courant** (poussé à la connexion puis à chaque changement)

```json
{
  "ph": 7.234,
  "orp": 718,
  "temperature": 24.5,
  "temperature_circuit": 28.1,
  "phCalPoints": 2,
  "orpCalPoints": 1,
  "filtration_running": true,
  "ph_dosing": false,
  "orp_dosing": false,
  "ph_daily_ml": 45.2,
  "orp_daily_ml": 120.5,
  "ph_regulation_mode": "automatic",
  "ph_daily_target_ml": 0,
  "orp_regulation_mode": "automatic",
  "orp_daily_target_ml": 0,
  "max_orp_ml_per_day": 1000,
  "orp_cal_valid": true,
  "reset_reason": "POWER_ON"
}
```

> **feature-021** : `ph` 3 décimales, ajout de `phCalPoints` (`-1..3`) et `orpCalPoints` (`-1..1`). Champs **supprimés** de la payload WS : `orp_raw`, `ph_raw`, `ph_voltage_mv`, `temperature_raw`. Voir [ADR-0014](adr/0014-migration-atlas-ezo.md).
>
> **feature-025** : `ph` / `orp` = valeur **filtrée** (fallback brut si non amorcé). Champs de filtrage ajoutés (voir tableau dédié ci-dessous).

Champs notables liés à la régulation pH :

| Champ | Type | Description |
|---|---|---|
| `ph_regulation_mode` | string | Mode actif : `"automatic"`, `"scheduled"` ou `"manual"` |
| `ph_daily_target_ml` | integer | Volume quotidien programmé (mL) — pertinent uniquement en mode `"scheduled"` |

Champ système :

| Champ | Type | Description |
|---|---|---|
| `reset_reason` | string | Raison du dernier reboot ESP32. Constant pendant tout le runtime. Valeurs possibles : `"POWER_ON"` (mise sous tension), `"SW_RESET"` (reboot logiciel, inclut les OTA), `"WATCHDOG"` (timeout watchdog matériel ou tâche), `"BROWNOUT"` (sous-tension), `"PANIC"` (exception / crash firmware), `"DEEP_SLEEP"` (réveil depuis veille profonde), `"EXTERNAL"` (signal RESET externe), `"UNKNOWN"` (autre). |

> Le champ `reset_reason` est absent des versions antérieures à la v2.5.x. L'UI se comporte gracieusement si le champ est absent (aucun toast affiché).

Champs notables liés à la régulation ORP :

| Champ | Type | Description |
|---|---|---|
| `orp_regulation_mode` | string | Mode actif : `"automatic"`, `"scheduled"` ou `"manual"` |
| `orp_daily_target_ml` | integer | Volume quotidien programmé de chlore (mL) — pertinent uniquement en mode `"scheduled"` |
| `max_orp_ml_per_day` | float | Limite journalière ORP (mL) — utilisée pour borner la saisie côté UI |
| `orp_cal_valid` | boolean | `true` si une calibration ORP a été enregistrée (depuis 2.0.0 : miroir de `orpCalPoints >= 1`) |

Champs ajoutés en feature-021 (calibration EZO) :

| Champ | Type | Description |
|---|---|---|
| `phCalPoints` | integer | Points de calibration EZO pH. `-1` = module injoignable / bus dégradé, `0` = non calibré, `1` = mid seul, `2` = mid + low (calibration nominale), `3` = mid + low + high. La régulation pH automatique est inhibée tant que la valeur est `< 2`. |
| `orpCalPoints` | integer | Points de calibration EZO ORP. `-1` = module injoignable, `0` = non calibré, `1` = calibré (Atlas ORP n'a qu'un seul point de calibration). La régulation ORP automatique est inhibée tant que la valeur est `< 1`. |

Champs ajoutés en feature-024 (pente sonde pH) :

| Champ | Type | Description |
|---|---|---|
| `phSlopeAcid` | float \| null | Pente acide EZO en % (1 décimale, idéal 100). `null` si jamais lu, bus dégradé ou EZO injoignable. |
| `phSlopeBase` | float \| null | Pente base EZO en % (1 décimale, idéal 100). `null` mêmes conditions. |
| `phSlopeZero` | float \| null | Décalage zéro EZO en mV (2 décimales, idéal 0). `null` si firmware EZO ancien ne le rapporte pas. |
| `phSlopeAgeMs` | integer \| null | Millisecondes depuis la dernière query `Slope,?` réussie. `null` si jamais lue depuis le boot (cohérent avec `phSlope*` nullables). L'UI considère l'état stale au-delà de 36 h. |

Champs ajoutés en feature-025 (lissage mesures + régulation P temporisée) :

| Champ | Type | Description |
|---|---|---|
| `phRaw` | float \| null | Dernière mesure pH **brute** Atlas (3 décimales). `null` si stale / jamais lue. |
| `phMedian` | float \| null | Médiane glissante pH (fenêtre 7). `null` si pas de donnée. |
| `phFiltered` | float \| null | pH **filtré** (médiane + EMA) — valeur utilisée par le PID et affichée en principal. `null` si non amorcé. |
| `phFilterReady` | boolean | `true` après warmup (≥ 5 mesures valides) **et** dernière mesure récente. Le dosage pH est bloqué tant que `false`. |
| `phFilterUnstable` | boolean | `true` si trop de rejets consécutifs (≥ 10) → capteur déclaré instable, dosage bloqué. |
| `phRejectedCount` | integer | Nombre de mesures pH rejetées (compteur glissant 0..255). |
| `orpRaw` / `orpMedian` / `orpFiltered` | float \| null | Équivalents ORP (mV, sans décimale). |
| `orpFilterReady` / `orpFilterUnstable` | boolean | Équivalents ORP. |
| `orpRejectedCount` | integer | Équivalent ORP. |
| `phMixingDelayActive` | boolean | `true` pendant la pause mélange hydraulique pH (15 min après injection). |
| `orpMixingDelayActive` | boolean | `true` pendant la pause mélange hydraulique ORP (20 min après injection). |
| `phDoseBlockedReason` | string \| null | Dernière cause de refus de `canDose(0)` (ex `"filtre capteur non prêt (warmup / EZO injoignable)"`, `"pause mélange en cours"`). `null` si dosage autorisé. |
| `orpDoseBlockedReason` | string \| null | Équivalent ORP. |

Champs ajoutés en feature-011 (répartition scheduled, v2.8.0 — [ADR-0021](adr/0021-repartition-scheduled.md)) :

| Champ | Type | Description |
|---|---|---|
| `ph_scheduled_flow_ml_per_min` | float \| null | Débit moyen **planifié** restant du mode Programmée pH (mL/min, 1 décimale) = volume restant à injecter / minutes de filtration restantes (bornées à minuit). `null` si le mode pH n'est pas `scheduled`, hors plage de filtration, ou heure locale ESP32 invalide — l'UI affiche alors « — ». |
| `orp_scheduled_flow_ml_per_min` | float \| null | Équivalent ORP (chlore). Mêmes conditions de nullité. |

Champs ajoutés en feature-056 (mode d'installation, v2.19.0 — [ADR-0026](adr/0026-mode-installation.md)) :

| Champ | Type | Description |
|---|---|---|
| `install_mode` | string | Mode d'installation actif : `"managed"` / `"powered"` / `"external"`. |
| `water_present` | boolean | Présence d'eau résolue (`resolveWaterPresent`), **source unique** des gardes de dosage. `managed` → filtration commandée ON ; `powered` → toujours `true` ; `external` → signal ON récent (< 180 s). |
| `filtration_state_source` | string | Origine de `water_present` : `"commanded"` (managed), `"powered"` (powered), `"external"` (external). |
| `filtration_state_stale` | boolean | Mode `external` uniquement : `true` si un signal a déjà été reçu mais qu'il est périmé (> 180 s) → dosage suspendu (fail-safe). |
| `filtration_ext_known` | boolean | Mode `external` : `true` dès qu'au moins un signal externe a été reçu depuis le boot (`false` = « aucun signal », fail-safe OFF). |
| `filtration_ext_on` | boolean | Dernier état signalé par la filtration externe (`ON`/`OFF`). |
| `filtration_ext_age_s` | integer | Âge en secondes du dernier signal externe (`0` si `filtration_ext_known` est `false`). |

> Le WebSocket pousse la configuration complète à la connexion initiale ; les mises à jour suivantes sont différentielles (seuls les champs modifiés sont inclus).

---

## Contrôle

### POST /pump1/on, /pump1/off — WRITE

Démarre ou arrête la pompe doseuse 1 (pH) manuellement (test bench).

```bash
curl -u admin:monmotdepasse -X POST http://poolcontroller.local/pump1/on
curl -u admin:monmotdepasse -X POST http://poolcontroller.local/pump1/off
```

> ⚠️ **Garde filtration (v2.1.2)** : `/pump1/on` retourne **`409 Conflict`** si la filtration est arrêtée et que `regulationMode != "continu"`. `/pump1/off` reste inconditionnel (pouvoir arrêter en toute circonstance).
>
> **v2.6.0** : le corps du 409 passe du texte brut au **JSON structuré** `{"error":"filtration_off","message":"…"}` — même format que les refus de `/ph/inject/start` (voir [tableau des codes](#codes-de-refus-409-v260)). Les routes de test `/pumpN/on` ne vérifient **que** la filtration (pas les limites volumétriques : pas de volume demandé), mais le temps de marche **consomme le budget horaire partagé** ([ADR-0020](adr/0020-budget-horaire-dosage-unique.md)).

---

### POST /pump2/on, /pump2/off — WRITE

Démarre ou arrête la pompe doseuse 2 (ORP/chlore) manuellement (test bench).

```bash
curl -u admin:monmotdepasse -X POST http://poolcontroller.local/pump2/on
curl -u admin:monmotdepasse -X POST http://poolcontroller.local/pump2/off
```

> ⚠️ **Garde filtration (v2.1.2)** : mêmes règles que `/pump1/on` ci-dessus.

---

### POST /pump1/duty/:duty, /pump2/duty/:duty — WRITE

Règle la puissance PWM d'une pompe (0–255).

```bash
curl -u admin:monmotdepasse -X POST http://poolcontroller.local/pump1/duty/128
```

---

### POST /ph/inject/start — WRITE

Démarre une injection manuelle pH à la puissance configurée (`pump1_max_duty_pct` ou `pump2_max_duty_pct` selon `ph_pump`). La durée est calculée à partir du volume demandé et du débit nominal de la pompe.

> ✅ **Injection manuelle gardée (v2.6.0, feature-006)** : le démarrage passe par les gardes de sécurité chimique de `evaluateManualInject()` ([`src/dosing_logic.h`](../src/dosing_logic.h)) — watchdog, filtration, stabilisation post-calibration, double démarrage, limite journalière **prédictive** (cumul + volume demandé), limite horaire (budget **partagé** avec la régulation auto, [ADR-0020](adr/0020-budget-horaire-dosage-unique.md)), cycles/jour et anti-rafale (ring partagé avec l'auto). Tout refus retourne **`409 Conflict`** avec un corps **JSON structuré** (voir [tableau des codes](#codes-de-refus-409-v260)). Le mode de régulation n'est volontairement **pas** vérifié (le manuel est disponible dans tous les modes), ni la mesure capteur (le manuel est aveugle à la mesure — assumé).
>
> Si la filtration s'arrête **pendant** l'injection, celle-ci est interrompue automatiquement (< 100 ms après détection) et une alerte MQTT `ph_injection_aborted` est publiée sur `{base}/alerts`. Pas de reprise automatique : l'utilisateur doit relancer manuellement après reprise filtration. `POST /ph/inject/stop` n'est **jamais** gardé (coupe-circuit opérateur).
>
> ✅ **Écrêtage automatique au reliquat journalier (v2.9.2)** : si le volume demandé (ou équivalent au `duration` legacy) **dépasse le reliquat** du quota journalier (`max_ph_ml_per_day − cumul`), la demande n'est plus refusée mais **écrêtée au reliquat** — durée recalculée arrondie **vers le bas** (le volume effectif ne re-déborde jamais la limite), log `info` `[Injection] pH : volume écrêté de X à Y mL (reliquat journalier)`, réponse `200 OK` normale. En fin naturelle, le crédit plancher (v2.9.1) porte le cumul **exactement à la limite** → latch `ph_limit_reached` + badge « Limite journalière atteinte ». Le refus `daily_limit` ne subsiste que si le reliquat est **nul ou < 1 s de pompe**. Cas double-clamp (reliquat > 10 min de pompe) : le plafond `kManualInjectMaxDurationS` gagne et le crédit retombe sur le volume effectif. Détail : [docs/subsystems/pump-controller.md](subsystems/pump-controller.md).

Paramètres (querystring, exclusifs) :

| Paramètre | Type | Validation |
|---|---|---|
| `volume` | float (mL) | 1 – 2000 (mode préféré) |
| `duration` | integer (secondes) | fallback legacy, borné **1 – 600** (`kManualInjectMaxDurationS`, abaissé de 3600 → 600 en v2.1.2 — voir CHANGELOG) |

```bash
curl -u admin:monmotdepasse -X POST "http://poolcontroller.local/ph/inject/start?volume=15"
```

Réponses :
- `200 OK` — injection démarrée (corps texte `OK`).
- `400` — paramètre manquant ou hors plage (corps texte).
- `409 Conflict` — garde de sécurité chimique déclenchée. Corps JSON structuré (ci-dessous).

#### Codes de refus 409 (v2.6.0)

Format du corps (`application/json`) :

```json
{ "error": "daily_limit", "message": "Limite journalière atteinte — reste disponible aujourd'hui : 10 mL.", "remaining_ml": 10 }
```

| `error` | Déclencheur (évalué dans cet ordre) | Champ additionnel |
|---|---|---|
| `watchdog_inactive` | Watchdog inactif sur la tâche de dosage (`loopTask`) — règle absolue | — |
| `filtration_off` | Filtration arrêtée et `regulationMode != "continu"` | — |
| `stabilization_in_progress` | Stabilisation post-calibration en cours **pour la pompe visée** | `seconds_remaining` (int) |
| `already_injecting` | Une injection manuelle est déjà en cours sur cette pompe (double start) | — |
| `daily_limit` | Reliquat journalier **nul ou < 1 s de pompe** (sinon la demande est **écrêtée** au reliquat et acceptée — v2.9.2 ; frontière `==` **acceptée** ; limite ≤ 0 = illimité) | `remaining_ml` (int, reliquat arrondi **vers le bas** depuis v2.9.2 — le message ne promet jamais plus que disponible) |
| `hourly_limit` | `usedMs + durée demandée > *_limit_minutes × 60000` (budget **partagé** auto + manuel ; frontière `==` acceptée ; limite 0 = illimité) | — |
| `max_cycles` | Cycles/jour atteints (`maxCyclesPerDay = 20`, compteur partagé auto + manuel) | — |
| `burst_limit` | Anti-rafale : ≥ 6 démarrages/min OU ≥ 20 démarrages/15 min (ring partagé auto + manuel) | — |

Le volume/durée évalués sont ceux **réellement injectés** (post-plafonnement `kManualInjectMaxDurationS`), pas la demande brute. Chaque refus émet un log `critical` `[Sécurité] Injection pH|ORP manuelle refusée : …`. Détail des gardes : [docs/subsystems/pump-controller.md](subsystems/pump-controller.md#gardes-des-injections-manuelles-feature-006).

---

### POST /ph/inject/stop — WRITE

Arrête immédiatement l'injection manuelle pH en cours.

```bash
curl -u admin:monmotdepasse -X POST http://poolcontroller.local/ph/inject/stop
```

---

### POST /orp/inject/start — WRITE

Identique à `/ph/inject/start` pour la pompe ORP (`orp_pump`). Mêmes paramètres et contraintes.

> ✅ **Injection manuelle gardée (v2.6.0, feature-006)** : mêmes gardes et même format de refus **`409` JSON** que `/ph/inject/start` — voir [tableau des codes](#codes-de-refus-409-v260). Limites appliquées côté ORP : `max_chlorine_ml_per_day` (journalière prédictive), `orp_limit_minutes` (horaire partagée avec l'auto), cycles/jour et anti-rafale (compteurs partagés), stabilisation post-cal ORP. Arrêt cyclique automatique si la filtration tombe en cours d'injection, alerte MQTT `orp_injection_aborted` publiée sur `{base}/alerts`. Bornage `duration` à 600 s (idem `/ph/inject/start`). **Écrêtage automatique au reliquat journalier (v2.9.2)** symétrique à la route pH (log `[Injection] ORP : volume écrêté de X à Y mL (reliquat journalier)`). `POST /orp/inject/stop` jamais gardé.

```bash
curl -u admin:monmotdepasse -X POST "http://poolcontroller.local/orp/inject/start?volume=50"
```

---

### POST /orp/inject/stop — WRITE

Arrête immédiatement l'injection manuelle ORP en cours.

```bash
curl -u admin:monmotdepasse -X POST http://poolcontroller.local/orp/inject/stop
```

---

### POST /lighting/on, /lighting/off — WRITE

Allume ou éteint l'éclairage (relais).

```bash
curl -u admin:monmotdepasse -X POST http://poolcontroller.local/lighting/on
curl -u admin:monmotdepasse -X POST http://poolcontroller.local/lighting/off
```

---

### POST /filtration/external-state — WRITE

Signale au contrôleur l'état réel d'une **filtration externe** (feature-056, v2.19.0). N'a d'effet utile qu'en mode d'installation `external` : il alimente la garde « présence d'eau » du dosage. Handler **non bloquant**, **aucune persistance** (au boot, état inconnu → dosage suspendu, fail-safe OFF).

Le paramètre `running` est accepté en **corps de formulaire** (`application/x-www-form-urlencoded`) OU en **query string** — valeurs acceptées : `true`/`false`/`1`/`0`/`on`/`off`. **Pas de corps JSON.**

```bash
# corps de formulaire
curl -u admin:monmotdepasse -X POST -d "running=true" \
  http://poolcontroller.local/filtration/external-state
# ou query string
curl -u admin:monmotdepasse -X POST \
  "http://poolcontroller.local/filtration/external-state?running=false"
```

**Réponse 200**

```json
{ "external_state": true }
```

**Erreurs**
- `400` : `{"error":"missing_param","message":"Paramètre 'running' requis (true/false)."}`
- `401` : token manquant / invalide

> Équivalent MQTT : publier `ON`/`OFF` sur `{base}/filtration_external_state/set` (voir [MQTT.md](MQTT.md)). Les deux canaux mettent à jour l'état de façon identique. Au-delà de `kExternalFiltrationStaleMs = 180 s` sans nouveau signal, l'état est considéré périmé → présence d'eau `false`. Voir [ADR-0026](adr/0026-mode-installation.md).

---

### POST /boost/start — WRITE

Active le **Mode Boost** (feature-053, v2.18.0) : surchloration temporaire du jour, auto-expirant au prochain minuit local. Tant qu'il est actif : filtration forcée en marche + cible ORP effective relevée (`min(orp_target + 60, 850)` mV) + limite journalière chlore effective relevée (`min(max_chlorine_ml_per_day × 1,5, 1000)` mL). **L'effet chlore ne s'applique qu'en mode de régulation ORP `automatic`** ; en Manuel / Programmé, seule la filtration s'étend. Aucun autre garde-fou n'est relâché. Voir [ADR-0025](adr/0025-mode-boost.md).

```bash
curl -u admin:monmotdepasse -X POST http://poolcontroller.local/boost/start
```

**Réponse 200** :

```json
{ "success": true, "boost_active": true, "boost_until": 1751846400, "filtration_extended": true, "chlorine_boosted": true }
```

Champs additifs v2.18.1 (feature-054) — indiquent quels leviers du Boost s'appliquent réellement selon la config :

| Champ | Type | Description |
|---|---|---|
| `filtration_extended` | boolean | `true` si la filtration est gérée par PoolController (`filtration_enabled`) → le Boost prolonge effectivement la filtration. `false` si filtration non gérée (levier inerte : le forçage Boost n'est jamais atteint). |
| `chlorine_boosted` | boolean | `true` si `orp_regulation_mode == "automatic"` → le Boost relève effectivement la cible/limite chlore. `false` en Manuel / Programmé (levier inerte : le chlore n'est pas relevé). |

Quand un levier est inerte, `startBoost()` logue en plus un `warning` (couvre l'activation HTTP **et** MQTT/HA — voir [pump-controller.md §Mode Boost](subsystems/pump-controller.md#mode-boost-feature-053)). L'activation n'est jamais bloquée (on informe, on n'empêche pas).

**Erreur 409** — heure non synchronisée : sans horloge valide, l'expiration à minuit ne peut être calculée, l'activation est refusée (pas de boost « sans fin »).

```json
{ "error": "time_not_synced", "message": "Heure non synchronisée — Boost indisponible." }
```

---

### POST /boost/stop — WRITE

Désactive le Mode Boost immédiatement. Retour intégral au comportement normal (cible ORP, limite journalière et filtration selon la configuration). Inconditionnel (jamais refusé).

```bash
curl -u admin:monmotdepasse -X POST http://poolcontroller.local/boost/stop
```

**Réponse 200** :

```json
{ "success": true, "boost_active": false }
```

---

## Calibration (Atlas EZO — feature-021)

Toutes les routes de calibration retournent **immédiatement** (`< 1 ms`) en mettant la commande dans la queue FreeRTOS de `SensorManager`. La commande s'exécute dans `loopTask` en ~900 ms (transaction I²C bloquante avec le module EZO). L'UI observe l'avancement via les champs WS `phCalPoints` / `orpCalPoints` rafraîchis automatiquement.

### POST /calibrate_ph — WRITE

Calibration EZO pH — déclenche `Cal,mid,7.00` (point milieu) ou `Cal,low,4.00` (point bas).

**Payload JSON :**

```json
{ "step": "mid" }    // ou { "step": "low" }
```

**Réponse 200** :

```json
{ "success": true, "queued": true, "step": "mid" }
```

**Erreurs** :
- `400 step must be 'mid' or 'low'` si payload invalide.
- `503 calibration queue saturée — réessayer dans 1s` si la queue (4 slots) est pleine.

```bash
curl -u admin:monmotdepasse -X POST -H "Content-Type: application/json" \
  -d '{"step":"mid"}' \
  http://poolcontroller.local/calibrate_ph
```

---

### POST /calibrate_orp — WRITE

Calibration EZO ORP — déclenche `Cal,<reference>` avec la référence en mV.

**Payload JSON :**

```json
{ "reference": 470 }
```

**Plage acceptée** : `0..1000` mV (couvre les standards usuels 225, 470, 650 mV).

**Réponse 200** :

```json
{ "success": true, "queued": true, "reference": 470 }
```

**Erreurs** :
- `400 reference must be 0..1000 mV` si valeur hors plage.
- `503 calibration queue saturée — réessayer dans 1s`.

```bash
curl -u admin:monmotdepasse -X POST -H "Content-Type: application/json" \
  -d '{"reference":470}' \
  http://poolcontroller.local/calibrate_orp
```

---

### POST /calibrate_clear — WRITE

Efface complètement la calibration EZO mémorisée dans le module (`Cal,clear`). À utiliser pour repartir d'une calibration vierge avant de refaire le workflow complet.

**Payload JSON :**

```json
{ "sensor": "ph" }    // ou { "sensor": "orp" }
```

**Réponse 200** :

```json
{ "success": true, "queued": true, "sensor": "ph" }
```

**Erreurs** :
- `400 sensor must be 'ph' or 'orp'`.
- `503 calibration queue saturée`.

```bash
curl -u admin:monmotdepasse -X POST -H "Content-Type: application/json" \
  -d '{"sensor":"ph"}' \
  http://poolcontroller.local/calibrate_clear
```

> **Routes legacy supprimées** (404 désormais) : `POST /calibrate_ph_neutral`, `POST /calibrate_ph_acid`, `POST /clear_ph_calibration`. Remplacées par les 3 routes ci-dessus. Voir [ADR-0014](adr/0014-migration-atlas-ezo.md).

---

## Mises à jour OTA

### POST /update — CRITICAL

Met à jour le firmware ou le filesystem via multipart/form-data.

```bash
# Firmware
curl -u admin:monmotdepasse -X POST \
  -F "update_type=firmware" -F "update=@.pio/build/esp32dev/firmware.bin" \
  http://poolcontroller.local/update

# Filesystem
curl -u admin:monmotdepasse -X POST \
  -F "update_type=filesystem" -F "update=@.pio/build/esp32dev/littlefs.bin" \
  http://poolcontroller.local/update
```

> ⚠️ `update_type` doit être envoyé **avant** le fichier dans le multipart.

**Champ POST optionnel `sha256`** (v2.11.0, [ADR-0022](adr/0022-verification-integrite-ota.md)) : empreinte SHA-256 attendue de l'image, avec ou sans préfixe `sha256:`. Si elle est fournie et ne correspond pas à l'empreinte calculée du flux reçu (ou si elle est malformée), le flash est **refusé** (`Update.abort()`, corps `FAIL`, log `CRITICAL`). Sans ce champ, l'empreinte calculée est simplement **loggée** (`info`) — flash autorisé (upload manuel, utilisateur présent).

```bash
curl -u admin:monmotdepasse -X POST \
  -F "update_type=firmware" -F "sha256=sha256:<64 hex>" \
  -F "update=@.pio/build/esp32dev/firmware.bin" \
  http://poolcontroller.local/update
```

Réponse : `200 OK` (corps `OK`) ou `200 OK` (corps `FAIL`).

**`409 Conflict`** (v2.11.0) : un upload est déjà en cours (une seule session d'upload à la fois — verrou anti-concurrence). Corps : `Upload refusé: une mise à jour OTA est déjà en cours`. Si le client d'un upload en cours se déconnecte, la session est annulée automatiquement et un nouvel upload redevient possible.

L'ESP32 redémarre automatiquement après une mise à jour réussie.

---

### GET /check-update — WRITE

Vérifie la dernière release disponible sur GitHub.

```bash
curl -u admin:monmotdepasse http://poolcontroller.local/check-update
```

```json
{
  "current_version": "1.0.3",
  "latest_version": "1.0.4",
  "update_available": true,
  "firmware_url": "https://github.com/.../firmware.bin",
  "filesystem_url": "https://github.com/.../littlefs.bin",
  "firmware_digest": "sha256:ab12…",
  "filesystem_digest": "sha256:cd34…"
}
```

Champs additifs v2.11.0 : `firmware_digest` / `filesystem_digest` — empreintes SHA-256 des assets (champ `digest` de l'API GitHub, format `sha256:<64 hex>`, chaîne vide si la release ne le fournit pas). L'UI les relaie en paramètre `digest=` de `/download-update` et **désactive le bouton Installer** si l'une des deux est vide (fail-closed).

---

### POST /download-update — CRITICAL

Télécharge et installe une mise à jour depuis une URL GitHub, avec vérification d'intégrité SHA-256 **obligatoire** (v2.11.0, [ADR-0022](adr/0022-verification-integrite-ota.md)).

```bash
curl -u admin:monmotdepasse -X POST \
  -H "Content-Type: application/x-www-form-urlencoded" \
  -d "url=https://github.com/.../firmware.bin&digest=sha256:<64 hex>&restart=true" \
  http://poolcontroller.local/download-update
```

> Seuls les hôtes `github.com`, `api.github.com` et `objects.githubusercontent.com` sont autorisés.

Paramètres POST :

| Paramètre | Requis | Description |
|---|---|---|
| `url` | oui | URL de l'asset (`firmware.bin` ou `littlefs.bin`, hôtes whitelistés) |
| `digest` | **oui** (v2.11.0) | Empreinte SHA-256 attendue, format `sha256:<64 hex>` (relayée depuis `/check-update`) |
| `restart` | non | `false` pour ne pas redémarrer après une installation filesystem réussie |

Erreurs d'intégrité (fail-closed) :

| Code | `error` | Cas |
|---|---|---|
| `400` | `integrity_digest_missing` | Paramètre `digest` absent — refus **avant** toute connexion |
| `400` | `integrity_digest_invalid` | Empreinte malformée (format attendu `sha256:<64 hex>`) |
| `422` | `integrity_mismatch` | Empreinte calculée du flux ≠ empreinte attendue (image corrompue ou tronquée, coupure WiFi incluse). Corps : `{"error","expected","computed","message"}`. **Firmware** : `Update.abort()` avant activation — version courante conservée. **Filesystem** : pas de redémarrage, partition FS à réinstaller (firmware intact). |

Chaque refus émet un log `CRITICAL` avec empreintes attendue/calculée.

---

## Diagnostic crash (coredump)

Ces trois endpoints permettent de consulter, télécharger et effacer le coredump ESP-IDF persisté dans la partition flash dédiée (`coredump`, 64 KB). Le dump est produit automatiquement par le firmware lors d'un crash de type `PANIC` (exception Xtensa) et persiste jusqu'à effacement explicite.

> Le contenu de la partition `coredump` **n'est pas effacé par les OTA** (firmware ou filesystem) ni par un factory reset.

### GET /coredump/info — WRITE

Retourne un résumé JSON du dernier coredump disponible.

```bash
curl -u admin:monmotdepasse http://poolcontroller.local/coredump/info
```

**Si un coredump est disponible :**

```json
{
  "available": true,
  "task": "loopTask",
  "pc": 1074038456,
  "exc_cause": 29,
  "exc_cause_str": "StoreProhibited",
  "exc_vaddr": 0
}
```

**Si aucun coredump n'est présent :**

```json
{
  "available": false,
  "partition_found": true
}
```

| Champ | Type | Description |
|---|---|---|
| `available` | boolean | `true` si un coredump valide a été trouvé dans la partition |
| `task` | string | Nom de la tâche FreeRTOS qui a crashé |
| `pc` | integer | Adresse du Program Counter au moment du crash (décimale) |
| `exc_cause` | integer | Code cause d'exception Xtensa (ex. 29 = `StoreProhibited`) |
| `exc_cause_str` | string | Libellé lisible de la cause d'exception |
| `exc_vaddr` | integer | Adresse mémoire ayant déclenché l'exception (accès invalide) |
| `partition_found` | boolean | `false` si la partition `coredump` est absente de la table de partitions |

---

### GET /coredump/download — WRITE

Télécharge le coredump brut sous forme de fichier binaire. Streamé via `AsyncCallbackResponse` sans allocation de 64 KB côté firmware.

```bash
curl -u admin:monmotdepasse http://poolcontroller.local/coredump/download -o coredump.bin
```

- **Content-Type** : `application/octet-stream`
- **Content-Disposition** : `attachment; filename="coredump.bin"`
- Retourne `404` si aucun coredump n'est disponible.

Pour décoder le fichier obtenu :

```bash
./tools/decode_coredump.sh coredump.bin
```

---

### DELETE /coredump — WRITE

Efface la partition `coredump` pour permettre l'enregistrement d'un prochain crash.

```bash
curl -u admin:monmotdepasse -X DELETE http://poolcontroller.local/coredump
```

```json
{ "success": true }
```

> ⚠️ L'effacement est irréversible. Télécharger le dump avant d'effacer.

---

## Système

### POST /reboot — CRITICAL

Redémarre l'ESP32.

```bash
curl -u admin:monmotdepasse -X POST http://poolcontroller.local/reboot
```

---

### POST /reboot-ap — CRITICAL

Efface les credentials WiFi et redémarre en mode point d'accès.

```bash
curl -u admin:monmotdepasse -X POST http://poolcontroller.local/reboot-ap
```

---

### POST /factory-reset — CRITICAL

Réinitialisation d'usine complète (efface la partition NVS).

```bash
curl -u admin:monmotdepasse -X POST http://poolcontroller.local/factory-reset
```

> Efface : mot de passe admin, token API, WiFi, MQTT, calibrations. Préserve : historique, fichiers LittleFS, **mot de passe AP WiFi** (l'étiquette sur le boîtier reste valide).

## Endpoints ajoutés en feature-020 (identification 2 sondes DS18B20, PCB v2)

Tous les endpoints `/sensors/onewire/*` requièrent l'auth (HTTP Basic + token).

### `GET /sensors/onewire/scan`

Liste les sondes DS18B20 actuellement détectées sur le bus OneWire (GPIO 5) avec leurs adresses ROM, T° brutes lues du cache (lecture rapide non bloquante) et leur rôle assigné.

```json
{
  "sondes": [
    { "address": "28FF1A2B3C4D5E6F", "temperature": 18.4, "role": "water" },
    { "address": "28FF9988776655AA", "temperature": 24.1, "role": "unknown" }
  ],
  "identified_count": 1,
  "detected_count": 2
}
```

`role` ∈ `"water" | "circuit" | "unknown"`. La T° peut être périmée jusqu'à `kPhOrpSensorIntervalMs` (~5 s) car le handler lit le cache mis à jour par `Sensors::update()` — pas de `requestTemperatures()` synchrone (qui prendrait 750 ms en 12-bit, > timeout 50 ms d'AsyncWebServer).

### `POST /sensors/onewire/identify`

Assigne une sonde à un rôle. **Auto-permutation activée** : si une autre sonde avait déjà le rôle demandé, elle bascule automatiquement à l'autre rôle.

Payload :

```json
{ "address": "28FF1A2B3C4D5E6F", "role": "water" }
```

Réponse : `{ "success": true }`. Erreurs : 400 si adresse hex invalide ou role hors `"water"|"circuit"` ; 404 si l'adresse n'est pas présente sur le bus.

### `POST /sensors/onewire/reset`

Efface l'identification persistée NVS (clés `ow_water_addr` et `ow_circuit_addr`). L'utilisateur devra refaire le workflow d'identification.

Payload : `{}` (objet vide). Réponse : `{ "success": true }`.

Voir [ADR-0013](adr/0013-identification-sondes-onewire.md) pour la décision d'identification + alternatives écartées.

## Endpoints ajoutés en feature-024 (pente sonde pH)

### `POST /debug/ph_slope_refresh` — pas d'auth (cohérent avec autres `/debug/*`)

Force une nouvelle interrogation `Slope,?` sur l'EZO pH sans attendre le cycle automatique 24 h ni une recalibration. Utile pour valider la chaîne de mesure ou une nouvelle calibration.

```bash
curl -X POST http://poolcontroller.local/debug/ph_slope_refresh
```

**Réponse 200** :

```json
{ "success": true, "queued": true }
```

**Réponse 503** (queue EZO pleine OU query déjà en attente) :

```json
{ "error": "queue full or already pending" }
```

L'UI page `/ph` (chip d'état sonde) utilise cet endpoint via le bouton « Rafraîchir » du modal détails. La nouvelle valeur arrive dans le payload WS dès que le handler EZO traite la commande (~1-2 s côté `loopTask`). Voir [feature-024](../specs/features/done/feature-024-pente-sonde-ph.md) et [`docs/features/page-ph.md`](features/page-ph.md#chip-détat-sonde-feature-024).

### `POST /debug/sensor_filter_reset` — pas d'auth (cohérent avec autres `/debug/*`)

Réinitialise **les deux** filtres pH et ORP (médiane + EMA). Les filtres repassent en **warmup** → le dosage automatique est bloqué jusqu'à ce que chaque filtre ait reçu `kSensorFilterWarmupSamples` (= 5) nouvelles mesures valides. Utile après un débranchement EZO, un test, ou une recalibration manuelle hors workflow.

```bash
curl -X POST http://poolcontroller.local/debug/sensor_filter_reset
```

**Réponse 200**

```json
{ "success": true, "reset": ["ph", "orp"] }
```

### `GET /debug/sensor_filter_state` — pas d'auth (cohérent avec autres `/debug/*`)

Retourne l'état brut des deux filtres pour diagnostic. Lecture lock-free des getters `SensorManager` (valeurs scalaires).

```bash
curl http://poolcontroller.local/debug/sensor_filter_state
```

**Réponse 200**

```json
{
  "ph":  { "raw": 7.241, "median": 7.236, "filtered": 7.234, "ready": true, "unstable": false, "rejected": 0 },
  "orp": { "raw": 722, "median": 720, "filtered": 720, "ready": true, "unstable": false, "rejected": 0 }
}
```

Les champs `raw` / `median` / `filtered` valent `null` si la mesure est indisponible. Voir [feature-025](../specs/features/done/feature-025-lissage-mesures-ph-orp-pid.md) et [`docs/subsystems/sensors.md`](subsystems/sensors.md#reset-manuel--diagnostic).

---

## Routes de debug supprimées (v2.5.0, feature-045)

Les routes suivantes, ajoutées pour la campagne de diagnostic d'oscillation pH (2026-05/06), ont été retirées et répondent désormais **404** :

- `GET /debug/ph_trace` et `POST /debug/ph_trace_clear` (trace ring buffer pH)
- `GET /debug/wifi_pause` et `POST /debug/wifi_pause` (pause WiFi temporaire)
- `POST /debug/ezo_command` et `POST /debug/ezo_factory` (diagnostic Atlas EZO)

Le code est récupérable via `git revert` du commit de la feature-045 ; l'état complet avec ces outils est figé au tag `v2.4.0`. Voir [feature-045](../specs/features/done/feature-045-retrait-outils-debug.md).

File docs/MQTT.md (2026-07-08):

# MQTT - ESP32 Pool Controller

## Configuration

| Paramètre | Description | Défaut |
|---|---|---|
| Serveur | Adresse du broker MQTT | — |
| Port | Port du broker | 1883 |
| Topic de base | Préfixe de tous les topics | `pool/sensors` |
| Utilisateur / Mot de passe | Authentification broker (optionnel) | — |

Configuration via **Paramètres → MQTT** dans l'interface web ou via `POST /save-config`.

---

## Topics publiés

Tous les topics utilisent le préfixe configurable (ex: `pool/sensors`). Les valeurs sont publiées avec **rétention** (retain=true) sauf indication contraire.

### Capteurs

| Topic | Payload | Description |
|---|---|---|
| `{base}/temperature` | `24.5` | Température de l'eau (°C) |
| `{base}/ph` | `7.234` | Valeur pH **filtrée** (médiane + EMA) depuis 2.2.0 — fallback brut si filtre non amorcé (**3 décimales** depuis 2.0.0 — voir [ADR-0014](adr/0014-migration-atlas-ezo.md)). Topics brut/médiane séparés ci-dessous (feature-025). |
| `{base}/orp` | `720` | Valeur ORP **filtrée** (mV) depuis 2.2.0 — fallback brut si filtre non amorcé |
| `{base}/ph_cal_points` | `2` | Points de calibration EZO pH (entier `-1..3`, `-1` = EZO injoignable). Retain. Voir [feature-021](../specs/features/done/feature-021-migration-atlas-ezo.md). |
| `{base}/orp_cal_points` | `1` | Points de calibration EZO ORP (entier `-1..1`, `-1` = EZO injoignable). Retain. |
| `{base}/ph_slope_acid` | `99.7` | Pente acide sonde pH EZO en % (1 décimale). Retain. Edge-triggered ([feature-024](../specs/features/done/feature-024-pente-sonde-ph.md)). |
| `{base}/ph_slope_base` | `100.3` | Pente base sonde pH EZO en % (1 décimale). Retain. Edge-triggered. |
| `{base}/ph_slope_zero` | `-0.89` | Décalage zéro sonde pH EZO en mV (2 décimales). Retain. Non publié si firmware EZO ancien. |

### Filtration

| Topic | Payload | Description |
|---|---|---|
| `{base}/install_mode` | `managed` / `powered` / `external` | **Mode d'installation** (feature-056, v2.19.0). Retain. Décrit le câblage : `managed` = PoolController pilote la filtration ; `powered` = alimenté par le circuit de filtration ; `external` = filtration tierce signalée. Valeurs brutes sur le fil ; le select HA les affiche traduites (voir feature-056 ci-dessous). Voir [ADR-0026](adr/0026-mode-installation.md). |
| `{base}/filtration_state` | `ON` / `OFF` | État du relais de filtration |
| `{base}/filtration_mode` | `auto` / `manual` / `force` / `off` | Mode de filtration courant (valeurs brutes sur le fil ; le select HA les affiche traduites — voir ci-dessous). Sémantique : `auto` = créneau calculé selon la température (heures en lecture seule) ; `manual` = **Programmation** (créneau à heures fixées par l'utilisateur) ; `force` = **Manuel** (contrôle ON/OFF sans planning) ; `off` = **Désactivé**. |
| `{base}/filtration_start` | `HH:MM` (ex. `08:00`) | Heure de début du créneau de filtration (feature-051, v2.16.0). Retain. En mode `auto`, recalculée selon la température (lecture seule) ; en mode `manual` (**Programmation**), heure fixée par l'utilisateur. |
| `{base}/filtration_end` | `HH:MM` (ex. `20:00`) | Heure de fin du créneau de filtration (feature-051, v2.16.0). Retain. Même sémantique. |

### Éclairage

| Topic | Payload | Description |
|---|---|---|
| `{base}/lighting_state` | `ON` / `OFF` | État du relais d'éclairage (contrôle manuel) |

### Boost (feature-053, v2.18.0)

| Topic | Payload | Description |
|---|---|---|
| `{base}/boost` | `ON` / `OFF` | État du **Mode Boost** (surchloration temporaire du jour). Retain. `ON` tant que le boost est actif ; retombe automatiquement à `OFF` au prochain minuit local (expiration). Voir [ADR-0025](adr/0025-mode-boost.md). |
| `{base}/lighting_schedule` | `ON` / `OFF` | Programmation horaire de l'éclairage active/inactive (feature-052, v2.17.0). Retain. Reflète le booléen `lightingCfg.scheduleEnabled`. Indépendant du relais manuel. Exposé en HA comme `select` « Mode Éclairage » (Programmation/Désactivé) via templates — le fil reste `ON`/`OFF` (bug-ha-eclairage-select, v2.17.2). |
| `{base}/lighting_start` | `HH:MM` (ex. `20:00`) | Heure de début du créneau d'éclairage (feature-052, v2.17.0). Retain. |
| `{base}/lighting_end` | `HH:MM` (ex. `23:30`) | Heure de fin du créneau d'éclairage (feature-052, v2.17.0). Retain. |

### Dosage

| Topic | Payload | Description |
|---|---|---|
| `{base}/ph_dosage` | `45.2` | Volume dosé pH aujourd'hui (ml) |
| `{base}/orp_dosage` | `120.5` | Volume dosé ORP/chlore aujourd'hui (ml) |
| `{base}/ph_dosing` | `ON` / `OFF` | Pompe doseuse pH en cours d'injection |
| `{base}/orp_dosing` | `ON` / `OFF` | Pompe doseuse ORP en cours d'injection |
| `{base}/ph_limit` | `ON` / `OFF` | Limite journalière pH atteinte |
| `{base}/orp_limit` | `ON` / `OFF` | Limite journalière ORP atteinte |
| `{base}/ph_stock_low` | `ON` / `OFF` | Volume pH restant sous le seuil d'alerte |
| `{base}/orp_stock_low` | `ON` / `OFF` | Volume chlore restant sous le seuil d'alerte |
| `{base}/ph_remaining_ml` | `1500` | Volume de produit pH restant dans le bidon (ml) |
| `{base}/orp_remaining_ml` | `3200` | Volume de produit chlore restant dans le bidon (ml) |
| `{base}/ph_daily_ml` | `45.2` | Cumul journalier injecté pH (mL) — retain, dédup au cycle 10 s, retombe à 0 à minuit (feature-050). Alimente l'entité HA `sensor` « Dosage pH aujourd'hui » |
| `{base}/orp_daily_ml` | `120.5` | Cumul journalier injecté chlore (mL) — retain, dédup au cycle 10 s, retombe à 0 à minuit (feature-050). Alimente l'entité HA `sensor` « Dosage Chlore aujourd'hui » |

### Consignes

| Topic | Payload | Description |
|---|---|---|
| `{base}/ph_target` | `7.2` | Consigne pH cible |
| `{base}/orp_target` | `700` | Consigne ORP cible (mV) |
| `{base}/ph_regulation_mode` | `automatic` / `scheduled` / `manual` | Mode de régulation pH actif — commandable via `{base}/ph_regulation_mode/set` depuis v2.7.0 (feature-009) |
| `{base}/ph_daily_target_ml` | `150` | Volume quotidien programmé pH (mL) — mode Programmée uniquement. Commandable via `{base}/ph_daily_target_ml/set` depuis v2.14.0 (feature-050) |
| `{base}/orp_regulation_mode` | `automatic` / `scheduled` / `manual` | Mode de régulation ORP actif — commandable via `{base}/orp_regulation_mode/set` depuis v2.7.0 |
| `{base}/orp_daily_target_ml` | `200` | Volume quotidien programmé chlore (mL) — mode Programmée uniquement. Commandable via `{base}/orp_daily_target_ml/set` depuis v2.14.0 (feature-050) |

### Système

| Topic | Payload | Rétention | Description |
|---|---|:---:|---|
| `{base}/status` | `online` / `offline` | Oui | Disponibilité (LWT) |
| `{base}/alerts` | JSON | Non | Alertes en temps réel |
| `{base}/logs` | Texte | Non | Messages de log |
| `{base}/diagnostic` | JSON | Oui | Snapshot complet du système |

> **`reset_reason` (raison du dernier reboot) :** ce champ est disponible uniquement via le **WebSocket** (`/ws`, champ `reset_reason` dans le message `sensor_data`). Il n'est pas publié via MQTT. Voir [`docs/API.md`](API.md#ws-ws--write) pour les valeurs possibles.

---

## Topics de commande (souscription)

| Topic | Payload accepté | Action |
|---|---|---|
| `{base}/filtration/set` | `ON` / `OFF` | Force marche/arrêt filtration |
| `{base}/install_mode/set` | `managed` / `powered` / `external` | Change le **mode d'installation** (feature-056, v2.19.0). Valeurs brutes attendues par le handler ; depuis HA le `command_template` retraduit le libellé français choisi. Valeur hors enum → ignorée + resync HA sur l'état réel. Appliqué sous `configMutex`, persisté NVS, republié (état + broadcast WS config). |
| `{base}/filtration_external_state/set` | `ON` / `OFF` | **Signal de filtration externe** (feature-056, v2.19.0). Non retain. Alimente la garde « présence d'eau » du dosage en mode `external` (équivalent de `POST /filtration/external-state`). `ON`/`OFF` insensible à la casse. **Aucune persistance** : au boot, état inconnu → dosage suspendu (fail-safe OFF) ; au-delà de 180 s sans nouveau signal → périmé → dosage suspendu. Voir [ADR-0026](adr/0026-mode-installation.md). |
| `{base}/filtration_mode/set` | `auto` / `manual` / `force` / `off` | Change le mode de filtration (valeurs brutes attendues par le handler ; depuis HA le `command_template` retraduit le libellé français choisi vers ces valeurs) |
| `{base}/filtration_start/set` | `HH:MM` (ex. `07:30`) | Change l'heure de début du créneau (feature-051, v2.16.0). Validée `HH:MM` via `timeStringToMinutes` (format invalide → ignoré + `warning` + resync HA sur la valeur réelle). Efface les overrides `forceOn`/`forceOff`, applique via `filtration.update()`, persisté NVS, republié. **Effet réel en mode Programmation** ; en mode **Auto** l'heure est recalculée par la température au prochain `update()` (saisie écrasée, consultation) |
| `{base}/filtration_end/set` | `HH:MM` (ex. `20:30`) | Change l'heure de fin du créneau (symétrique, feature-051, v2.16.0) |
| `{base}/lighting/set` | `ON` / `OFF` | Allume/éteint l'éclairage (contrôle manuel du relais) |
| `{base}/boost/set` | `ON` / `OFF` | Active / désactive le **Mode Boost** (feature-053, v2.18.0). `ON` → active la surchloration temporaire du jour (filtration forcée + cible/limite chlore effectives relevées, cf. [ADR-0025](adr/0025-mode-boost.md)) ; `OFF` → désactive. **L'activation est refusée si l'heure n'est pas synchronisée** (l'expiration à minuit ne peut être calculée) → aucun changement + resync HA sur l'état réel. Payload invalide ignoré. Expire automatiquement au prochain minuit local. |
| `{base}/lighting_schedule/set` | `ON` / `OFF` | Active/désactive la programmation horaire (feature-052, v2.17.0). Payload validé `ON`/`OFF` (insensible à la casse) → `lightingCfg.scheduleEnabled` ; invalide → ignoré + `warning` + resync HA. Persisté NVS, appliqué via `lighting.update()`, republié. Broadcast WS config vers l'UI web |
| `{base}/lighting_start/set` | `HH:MM` (ex. `20:00`) | Change l'heure de début du créneau (feature-052, v2.17.0). Validée `HH:MM` via `timeStringToMinutes` (format invalide → ignoré + `warning` + resync HA). Pilote `lightingCfg.startTime`, persisté NVS, appliqué, republié |
| `{base}/lighting_end/set` | `HH:MM` (ex. `23:30`) | Change l'heure de fin du créneau (symétrique, `lightingCfg.endTime`, feature-052, v2.17.0) |
| `{base}/ph_target/set` | `7.2` (6.0 – 8.5) | Change la consigne pH |
| `{base}/orp_target/set` | `700` (400 – 900) | Change la consigne ORP (mV) |
| `{base}/ph_regulation_mode/set` | `automatic` / `scheduled` / `manual` | Change le mode de régulation pH (feature-009, v2.7.0). Insensible à la casse. Valeur hors enum → ignorée + log `warning` |
| `{base}/orp_regulation_mode/set` | `automatic` / `scheduled` / `manual` | Change le mode de régulation ORP (idem) |
| `{base}/ph_daily_target_ml/set` | `150` (0 – 2000 mL, entier) | Change le volume quotidien programmé pH (feature-050, v2.14.0). Payload non numérique → ignoré + log `warning` ; négatif → clampé à 0 ; **valeur > limite journalière VIVE `maxPhMlPerDay` → refusée** + `warning` + resync HA. Persisté NVS, republié |
| `{base}/orp_daily_target_ml/set` | `500` (0 – 2000 mL, entier) | Change le volume quotidien programmé chlore (symétrique pH). Refus si > limite journalière VIVE `maxChlorineMlPerDay` |
| `{base}/reboot/set` | `PRESS` (tout payload accepté) | Redémarre le contrôleur (feature-050, v2.14.0). Non retain. Redémarrage **différé propre** : flush MQTT `offline` puis restart, même séquence que la route `POST /reboot` |

---

## Alertes

Topic : `{base}/alerts` — QoS 0, sans rétention.

```json
{
  "type": "ph_abnormal",
  "message": "pH=4.8",
  "timestamp": 12345678
}
```

| Type | Condition |
|---|---|
| `ph_limit` | Limite journalière de dosage pH atteinte — émise **une seule fois, à la transition** vers la limite (v2.10.1 ; avant : répétée à chaque health check de 60 s). Événement non-retained : l'**état permanent** pour HA est porté par le binary_sensor `{base}/ph_limit` (retain). Libellé dynamique « pH+ » / « pH- » selon le produit configuré (`phCorrectionType`). Après un reboot avec limite déjà latchée : une alerte unique au premier health check (~60 s), comportement voulu. |
| `orp_limit` | Limite journalière de dosage ORP atteinte — même sémantique de transition que `ph_limit` (v2.10.1) ; état permanent : binary_sensor `{base}/orp_limit` (retain). |
| `ph_abnormal` | pH < 5.0 ou pH > 9.0 |
| `orp_abnormal` | ORP < 400 mV ou ORP > 900 mV |
| `temp_abnormal` | Température < 5°C ou > 40°C |
| `low_memory` | Mémoire heap disponible sous le seuil |
| `ph_injection_aborted` | Injection manuelle pH interrompue par la sécurité chimique : la filtration s'est arrêtée pendant l'injection (v2.1.2). Pas de reprise auto, l'utilisateur doit relancer manuellement après reprise filtration. |
| `orp_injection_aborted` | Injection manuelle ORP/chlore interrompue par la sécurité chimique (mêmes conditions que `ph_injection_aborted`). |

### Alertes dédiées (feature-021 / feature-022, retain, edge-triggered)

Ces topics sont **retain** : le dernier état persiste sur le broker même après un reboot. Une **payload vide** publiée en retain efface l'alerte (clear) — utile pour HA qui peut alors retirer le badge automatiquement.

| Topic | Payload alerte | Payload clear | Condition de bascule |
|---|---|---|---|
| `{base}/alerts/calibration_required` | JSON `{"type":"calibration_required","phCalPoints":<int>,"orpCalPoints":<int>,"timestamp":<ms>}` | (vide) | Bascule **alerte** : `phCalPoints < 2` OU `orpCalPoints < 1`. Bascule **clear** : les deux capteurs OK. |
| `{base}/alerts/sensor_stale` | JSON `{"type":"sensor_stale","phStale":<bool>,"orpStale":<bool>,"timestamp":<ms>}` | (vide) | Bascule **alerte** : `getPh()` ou `getOrp()` retourne NaN (lecture > `kSensorStaleTimeoutMs = 20 s`). Bascule **clear** : les deux lectures redeviennent valides. |
| `{base}/alerts/sensor_frozen` | JSON `{"type":"sensor_frozen","phFrozen":<bool>,"orpFrozen":<bool>,"timestamp":<ms>}` | (vide) | Bascule **alerte** : capteur pH ou ORP **figé** (variance nulle sur 30 lectures — feature-022, v2.10.0). Bascule **clear** : les deux capteurs redeviennent vivants. La température figée (warning-only) n'est **pas** dans ce payload. |

Publication **edge-triggered** : un message n'est émis qu'à la transition (entrée ou sortie de l'état d'alerte), pas à chaque cycle MQTT. Voir [`docs/subsystems/sensors.md`](subsystems/sensors.md) et [`docs/subsystems/mqtt-manager.md`](subsystems/mqtt-manager.md).

---

## Diagnostic

Topic : `{base}/diagnostic` — publié au démarrage et à chaque reconnexion.

```json
{
  "uptime_ms": 123456789,
  "uptime_min": 2057,
  "free_heap": 45230,
  "wifi_ssid": "MonWiFi",
  "wifi_rssi": -65,
  "ip_address": "192.168.1.100",
  "sensors_initialized": true,
  "ph_value": 7.2,
  "orp_value": 720,
  "temperature": 24.5,
  "ph_dosing_active": false,
  "orp_dosing_active": false,
  "ph_daily_ml": 45.2,
  "orp_daily_ml": 120.5,
  "ph_limit_reached": false,
  "orp_limit_reached": false,
  "filtration_running": true,
  "filtration_mode": "auto",
  "ph_target": 7.2,
  "orp_target": 700.0,
  "firmware_version": "1.0.3"
}
```

---

## Home Assistant Auto-Discovery

Le contrôleur publie automatiquement sa configuration pour Home Assistant au démarrage.

**Préfixe discovery :** `homeassistant/`
**Device ID :** `poolcontroller`

| Type | Nom dans HA | Topic état | Topic commande |
|---|---|---|---|
| Sensor | Piscine Température | `{base}/temperature` | — |
| Sensor | Piscine pH | `{base}/ph` | — |
| Sensor | Piscine ORP | `{base}/orp` | — |
| Sensor | Piscine pH Points Calibrés | `{base}/ph_cal_points` | — |
| Sensor | Piscine ORP Points Calibrés | `{base}/orp_cal_points` | — |
| Binary Sensor | Filtration Active | `{base}/filtration_state` | — |
| Binary Sensor | Dosage pH Actif | `{base}/ph_dosing` | — |
| Binary Sensor | Dosage Chlore Actif | `{base}/orp_dosing` | — |
| Binary Sensor | Limite Journalière pH | `{base}/ph_limit` | — |
| Binary Sensor | Limite Journalière Chlore | `{base}/orp_limit` | — |
| Binary Sensor | Stock pH Faible | `{base}/ph_stock_low` | — |
| Binary Sensor | Stock Chlore Faible | `{base}/orp_stock_low` | — |
| Binary Sensor | Capteur pH — problème | `{base}/ph_sensor_problem` | — |
| Binary Sensor | Capteur ORP — problème | `{base}/orp_sensor_problem` | — |
| Sensor | Volume pH Restant | `{base}/ph_remaining_ml` | — |
| Sensor | Volume Chlore Restant | `{base}/orp_remaining_ml` | — |
| Binary Sensor | Contrôleur Status | `{base}/status` | — |
| Select | Mode d'installation | `{base}/install_mode` | `{base}/install_mode/set` |
| Switch | Signal filtration externe | — (optimiste) | `{base}/filtration_external_state/set` |
| Select | Mode Filtration | `{base}/filtration_mode` | `{base}/filtration_mode/set` |
| Text | Filtration début | `{base}/filtration_start` | `{base}/filtration_start/set` |
| Text | Filtration fin | `{base}/filtration_end` | `{base}/filtration_end/set` |
| Select | Mode Régulation pH | `{base}/ph_regulation_mode` | `{base}/ph_regulation_mode/set` |
| Select | Mode Régulation ORP | `{base}/orp_regulation_mode` | `{base}/orp_regulation_mode/set` |
| Switch | Filtration Marche/Arrêt | `{base}/filtration_state` | `{base}/filtration/set` |
| Switch | Éclairage Piscine | `{base}/lighting_state` | `{base}/lighting/set` |
| Switch | Boost | `{base}/boost` | `{base}/boost/set` |
| Select | Mode Éclairage | `{base}/lighting_schedule` | `{base}/lighting_schedule/set` |
| Text | Éclairage début | `{base}/lighting_start` | `{base}/lighting_start/set` |
| Text | Éclairage fin | `{base}/lighting_end` | `{base}/lighting_end/set` |
| Number | Consigne pH | `{base}/ph_target` | `{base}/ph_target/set` |
| Number | Consigne ORP | `{base}/orp_target` | `{base}/orp_target/set` |
| Sensor | Dosage pH aujourd'hui | `{base}/ph_daily_ml` | — |
| Sensor | Dosage Chlore aujourd'hui | `{base}/orp_daily_ml` | — |
| Number | Volume quotidien pH | `{base}/ph_daily_target_ml` | `{base}/ph_daily_target_ml/set` |
| Number | Volume quotidien Chlore | `{base}/orp_daily_target_ml` | `{base}/orp_daily_target_ml/set` |
| Button | Redémarrer | — | `{base}/reboot/set` |

> **Compatibilité `orp_enabled` :** le champ `orp_enabled` (booléen) est maintenu comme miroir de `orp_regulation_mode` (`true` si mode ≠ `manual`). Les automations Home Assistant qui testent la valeur de ce champ continuent de fonctionner sans modification. Le topic `{base}/orp_regulation_mode` est la source de vérité pour le mode actif.

> **Libellés du select « Mode Filtration » (bug-ha-filtration-mode-labels, v2.15.0) :** dans Home Assistant, ce select expose les libellés français **Auto / Programmation / Manuel / Désactivé** (alignés sur l'UI web), et non plus les valeurs brutes anglaises. La traduction est purement côté HA via templates de la discovery : `value_template` mappe l'état brut publié (`auto`/`manual`/`force`/`off`) vers le libellé affiché (avec `.get(value, value)` → un état inattendu passe sans casser), `command_template` mappe le libellé choisi vers la valeur brute envoyée sur `.../set`. **Le protocole MQTT sur le fil reste strictement `auto`/`manual`/`force`/`off`** (état publié comme commande attendue par `drainCommandQueue`) : aucune automatisation existante n'est cassée. Levée d'ambiguïté : `manual` = « Programmation » (créneau à heures fixées), `force` = « Manuel » (contrôle ON/OFF sans planning). Les selects `ph`/`orp_regulation_mode` affichent depuis v2.17.3 les libellés français **Automatique / Programmée / Manuelle** via la même technique (le fil reste `automatic`/`scheduled`/`manual`, voir bug-ha-regulation-mode-labels ci-dessous).

> **Select « Mode Éclairage » (bug-ha-eclairage-select, v2.17.2) :** la programmation horaire de l'éclairage était exposée en `switch` ON/OFF. Elle est désormais un `select` « Mode Éclairage » avec les libellés **Programmation / Désactivé**, pour cohérence visuelle avec le select « Mode Filtration ». Même technique que ce dernier : `value_template` (`{'ON':'Programmation','OFF':'Désactivé'}.get(value, value)`) et `command_template` (`{'Programmation':'ON','Désactivé':'OFF'}`) traduisent l'affichage HA. **Le protocole MQTT sur le fil reste strictement `ON`/`OFF`** ; le booléen `lightingCfg.scheduleEnabled` et le handler `lighting_schedule` (reçoit toujours ON/OFF) sont **inchangés**. `unique_id` conservé (`poolcontroller_lighting_schedule`). Migration : un payload retain vide est publié une fois sur l'ancien topic `homeassistant/switch/{HA_DEVICE_ID}_lighting_schedule/config` pour retirer le switch orphelin de HA.

## Topic et entité ajoutés en feature-020 (PCB v2)

| Topic | Description | Retain | Auto-discovery HA |
|---|---|---|---|
| `{base}/temperature_circuit` | T° de la sonde DS18B20 « circuit électronique » (NaN/null si non identifiée) | true | `sensor` "Piscine Température Circuit", `device_class: temperature`, `unit: °C`, `state_class: measurement` |

Le topic `{base}/temperature` (eau piscine) et son entité « Piscine Température » restent **inchangés** (rétrocompat HA).

Le bus OneWire (GPIO 5) supporte 2 sondes DS18B20 sur le PCB v2. Chaque sonde a un rôle (eau/circuit) identifié via Paramètres → Avancé. Voir [ADR-0013](adr/0013-identification-sondes-onewire.md).

## Topics et entités ajoutés en feature-021 (Atlas EZO pH/ORP, PCB v2)

| Topic | Description | Retain | Auto-discovery HA |
|---|---|---|---|
| `{base}/ph_cal_points` | Nombre de points calibrés EZO pH (-1 = injoignable, 0..3 sinon) | true | `sensor` "Piscine pH Points Calibrés" — `unique_id: poolcontroller_ph_cal_points`, `icon: mdi:numeric` |
| `{base}/orp_cal_points` | Nombre de points calibrés EZO ORP (-1 = injoignable, 0..1 sinon) | true | `sensor` "Piscine ORP Points Calibrés" — `unique_id: poolcontroller_orp_cal_points`, `icon: mdi:numeric` |
| `{base}/alerts/calibration_required` | Alerte calibration EZO incomplète. JSON ou payload vide (clear). | true | aucun (pour automation HA personnalisée) |
| `{base}/alerts/sensor_stale` | Alerte lecture pH/ORP stale (NaN > 20 s). JSON ou payload vide (clear). | true | aucun |

**Précision pH** : le topic `{base}/ph` publie désormais avec **3 décimales** (vs 1 décimale en v1.x). Tout consommateur HA qui parsait `int()` doit basculer sur `float()` ; les sensors HA standards (`device_class: ph`) gèrent cela nativement.

**Topics inchangés** (rétrocompat HA) : `{base}/orp`, `{base}/ph_target`, `{base}/orp_target`, `{base}/ph_dosing`, `{base}/orp_dosing`, `{base}/ph_limit`, `{base}/orp_limit`, `{base}/ph_regulation_mode`, `{base}/orp_regulation_mode`, etc. Les topics et entités HA de calibration ORP héritées (notamment `orp_cal_valid`) restent diffusés pour compatibilité, mais leur source de vérité côté firmware est désormais le module EZO (`orp_cal_points >= 1`).

Voir [ADR-0014](adr/0014-migration-atlas-ezo.md) (décision migration) et [`docs/subsystems/sensors.md`](subsystems/sensors.md) (détails techniques EZO + cache cal_points).

## Topics et entités ajoutés en feature-024 (pente sonde pH)

Diagnostic d'usure de la sonde pH via la commande Atlas `Slope,?`. Toutes les valeurs sont **strictement diagnostiques** — elles n'affectent ni `canDose()` ni le PID. L'évaluation des seuils (sonde excellente / correcte / usée / à remplacer) est faite côté UI, pas en firmware.

| Topic | Description | Retain | Auto-discovery HA |
|---|---|---|---|
| `{base}/ph_slope_acid` | Pente acide en % (1 décimale, idéal 100 %) | true | `sensor` "Piscine pH Pente Acide" — `unique_id: poolcontroller_ph_slope_acid`, `unit: %`, `icon: mdi:angle-acute`, `state_class: measurement` |
| `{base}/ph_slope_base` | Pente base en % (1 décimale, idéal 100 %) | true | `sensor` "Piscine pH Pente Base" — `unique_id: poolcontroller_ph_slope_base`, `unit: %`, `icon: mdi:angle-obtuse`, `state_class: measurement` |
| `{base}/ph_slope_zero` | Décalage zéro en mV (2 décimales, idéal 0). Non publié tant que NaN — peut rester absent sur firmware EZO ancien qui ne renvoie que 2 floats. | true | `sensor` "Piscine pH Décalage Zéro" — `unique_id: poolcontroller_ph_slope_zero`, `unit: mV`, `icon: mdi:sine-wave`, `state_class: measurement` |

**Publication edge-triggered** : un message n'est émis qu'à la transition de la valeur **arrondie** (1 décimale pour les pentes, 2 pour le zéro). Pas de spam à chaque cycle — la query `Slope,?` n'est elle-même rafraîchie qu'au boot, après calibration EZO et toutes les 24 h.

**Pas de `binary_sensor` "à remplacer"** côté firmware : l'utilisateur peut le créer en automation HA depuis les 3 sensors selon ses propres seuils (par défaut UI : pente min ≥ 95 % et |zéro| ≤ 15 mV → vert ; < 85 % ou |zéro| > 30 mV → rouge).

Voir [`docs/features/page-ph.md`](features/page-ph.md#chip-détat-sonde-feature-024) (chip + modal UI) et [`docs/subsystems/sensors.md`](subsystems/sensors.md#pente-sonde-ph--feature-024) (détails firmware : cache, fail streak, refresh policy).

## Topics et entités ajoutés en feature-025 (lissage mesures pH/ORP)

Lissage logiciel des mesures (médiane 7 + EMA). Le topic `{base}/ph` / `{base}/orp` publie désormais la valeur **filtrée** (cf. tableau Capteurs ci-dessus) ; les topics ci-dessous exposent en plus le brut, la médiane et l'état du filtre pour diagnostic EMI. Tous **retain**.

| Topic | Payload | Description |
|---|---|---|
| `{base}/ph_raw` | `7.46` | Dernière mesure pH **brute** Atlas (diagnostic EMI, 3 décimales) |
| `{base}/ph_median` | `7.43` | Médiane glissante pH (fenêtre 7) |
| `{base}/ph_filtered` | `7.43` | Mesure pH **filtrée** (EMA) — valeur de régulation |
| `{base}/ph_filter_ready` | `ON`/`OFF` | Filtre pH prêt (warmup terminé + mesure récente) |
| `{base}/ph_filter_unstable` | `ON`/`OFF` | Capteur pH instable (trop de rejets consécutifs) |
| `{base}/ph_rejected_count` | `3` | Nombre de mesures pH rejetées (glissant, 0..255) |
| `{base}/orp_raw` | `690` | Dernière mesure ORP **brute** Atlas (mV) |
| `{base}/orp_median` | `682` | Médiane glissante ORP (mV) |
| `{base}/orp_filtered` | `682` | Mesure ORP **filtrée** (mV) — valeur de régulation |
| `{base}/orp_filter_ready` | `ON`/`OFF` | Filtre ORP prêt |
| `{base}/orp_filter_unstable` | `ON`/`OFF` | Capteur ORP instable |
| `{base}/orp_rejected_count` | `2` | Nombre de mesures ORP rejetées |
| `{base}/ph_mixing_delay_active` | `ON`/`OFF` | Pause mélange pH active (15 min après injection) |
| `{base}/orp_mixing_delay_active` | `ON`/`OFF` | Pause mélange ORP active (20 min après injection) |

### Auto-discovery HA (feature-025)

| Entité | Type | Topic d'état | `unique_id` | Détails |
|---|---|---|---|---|
| Piscine pH Brut | `sensor` | `{base}/ph_raw` | `poolcontroller_ph_raw` | `unit: pH`, `icon: mdi:water-outline`, `state_class: measurement` |
| Piscine pH Filtré | `sensor` | `{base}/ph_filtered` | `poolcontroller_ph_filtered` | `unit: pH`, `icon: mdi:water-check`, `state_class: measurement` |
| Piscine ORP Brut | `sensor` | `{base}/orp_raw` | `poolcontroller_orp_raw` | `unit: mV`, `icon: mdi:flash-outline`, `state_class: measurement` |
| Piscine ORP Filtré | `sensor` | `{base}/orp_filtered` | `poolcontroller_orp_filtered` | `unit: mV`, `icon: mdi:flash-alert`, `state_class: measurement` |
| Piscine Filtre pH Prêt | `binary_sensor` | `{base}/ph_filter_ready` | `poolcontroller_ph_filter_ready` | `payload_on: ON`, `payload_off: OFF`, `icon: mdi:filter-check` |
| Piscine Filtre ORP Prêt | `binary_sensor` | `{base}/orp_filter_ready` | `poolcontroller_orp_filter_ready` | `payload_on: ON`, `payload_off: OFF`, `icon: mdi:filter-check` |

> Le préfixe réel `unique_id` est `HA_DEVICE_ID` (`poolcontroller`). Les topics `median`, `filter_unstable`, `rejected_count` et `mixing_delay_active` sont publiés en retain mais **sans** entité auto-discovery dédiée (l'utilisateur peut créer des sensors HA manuels s'il le souhaite). Voir [`src/mqtt_manager.cpp`](../src/mqtt_manager.cpp) et [`docs/subsystems/sensors.md`](subsystems/sensors.md#filtrage-des-mesures-phorp--feature-025).

## Entités ajoutées en feature-009 (modes de régulation commandables, v2.7.0)

Deux entités HA `select` permettent de changer le mode de régulation pH / ORP depuis Home Assistant (automatisation « hivernage », détection d'absence, dashboard HA, etc.) :

| Entité | Discovery topic | `state_topic` | `command_topic` | Détails |
|---|---|---|---|---|
| Mode Régulation pH | `homeassistant/select/poolcontroller_ph_regulation_mode/config` | `{base}/ph_regulation_mode` | `{base}/ph_regulation_mode/set` | `unique_id: poolcontroller_ph_regulation_mode`, `icon: mdi:ph`, `options: ["Automatique","Programmée","Manuelle"]` + templates (voir note ci-dessous) |
| Mode Régulation ORP | `homeassistant/select/poolcontroller_orp_regulation_mode/config` | `{base}/orp_regulation_mode` | `{base}/orp_regulation_mode/set` | `unique_id: poolcontroller_orp_regulation_mode`, `icon: mdi:flash`, mêmes options + templates |

> **Libellés français des selects Mode Régulation pH/ORP (bug-ha-regulation-mode-labels, v2.17.3) :** dans Home Assistant, ces deux selects exposent les libellés français **Automatique / Programmée / Manuelle** (libellés exacts de l'UI web), et non plus les valeurs brutes anglaises. Même technique que les selects « Mode Filtration » et « Mode Éclairage » : `value_template` (`{'automatic':'Automatique','scheduled':'Programmée','manual':'Manuelle'}.get(value, value)`) mappe l'état brut publié vers le libellé, `command_template` (`{'Automatique':'automatic','Programmée':'scheduled','Manuelle':'manual'}[value]`) retraduit le libellé choisi vers la valeur brute envoyée sur `.../set`. **Le protocole MQTT sur le fil reste strictement `automatic` / `scheduled` / `manual`** (topics d'état et handlers `PhRegulationMode` / `OrpRegulationMode` inchangés) : aucune automatisation Home Assistant existante n'est cassée.

Comportement :

- **Topics state inchangés** (retain, format existant) — rétrocompat totale des dashboards HA existants. Les topics de commande `.../set` sont **non retain**.
- **Validation stricte** de l'enum (comparaison après normalisation en minuscules) : toute valeur hors `automatic` / `scheduled` / `manual` est **ignorée** avec un log `warning` (« Mode régulation pH/ORP invalide (MQTT): ... »), aucun republish.
- **Même voie que l'UI web** : application sous `configMutex`, miroir booléen `ph_enabled` / `orp_enabled` mis à jour (`true` si mode ≠ `manual`, voir [ADR-0004](adr/0004-mode-regulation-enum-3-valeurs.md)), persistance NVS **uniquement si changement réel**. Republication immédiate de l'état (feedback HA).
- **Changement pendant une injection en cours** : l'injection se termine naturellement, le nouveau mode prend effet au cycle de régulation suivant.
- Pas de `switch` HA séparé pour `ph_enabled` / `orp_enabled` : le `select` est la source de vérité (les miroirs booléens restent publiés pour rétrocompat).

Voir [`docs/subsystems/mqtt-manager.md`](subsystems/mqtt-manager.md#gestion-des-commandes-ha-reçues) (handler) et [`docs/features/page-ph.md`](features/page-ph.md#interaction-mqtt) / [`page-orp.md`](features/page-orp.md#interaction-mqtt).

## Topics et entités ajoutés en feature-022 (problème capteur pH/ORP, v2.10.0)

Observabilité de l'indisponibilité capteur pour Home Assistant : un état binaire **par capteur**, directement consommable par un `binary_sensor` HA sans parser les JSON d'alerte.

### États binaires `{base}/ph_sensor_problem` / `{base}/orp_sensor_problem`

| Topic | Payload | Retain | Condition |
|---|---|:---:|---|
| `{base}/ph_sensor_problem` | `ON` / `OFF` | oui | `ON` si le capteur pH est **stale** (lecture NaN > 20 s, cf. `alerts/sensor_stale`) **OU figé** (variance nulle, cf. `alerts/sensor_frozen`). `OFF` sinon. |
| `{base}/orp_sensor_problem` | `ON` / `OFF` | oui | Symétrique ORP. |

Publication **dédupliquée** : le message n'est émis qu'au changement d'état (cache mémorisé, première publication forcée après connexion). Retain → HA retrouve l'état après un reboot du contrôleur ou de HA.

### Auto-discovery HA

| Entité | Type | Topic d'état | `unique_id` | Détails |
|---|---|---|---|---|
| Capteur pH — problème | `binary_sensor` | `{base}/ph_sensor_problem` | `poolcontroller_ph_sensor_problem` | `device_class: problem`, `payload_on: ON`, `payload_off: OFF`, `icon: mdi:alert` |
| Capteur ORP — problème | `binary_sensor` | `{base}/orp_sensor_problem` | `poolcontroller_orp_sensor_problem` | `device_class: problem`, mêmes payloads/icône |

### Alerte `{base}/alerts/sensor_frozen`

Calquée sur `alerts/sensor_stale` (retain, edge-triggered, clear = payload vide) — voir le tableau [Alertes dédiées](#alertes-dédiées-feature-021--feature-022-retain-edge-triggered). Publiée à la transition **figé** d'au moins un capteur pH/ORP :

```json
{ "type": "sensor_frozen", "phFrozen": true, "orpFrozen": false, "timestamp": 12345678 }
```

Un capteur figé (30 lectures acceptées dans une bande < ½ LSB, ≈ 2,5 min) rend le filtre non prêt → **dosage automatique bloqué fail-closed** (garde `FilterNotReady` existante). La **température figée** (détection warning-only, aucun impact dosage) n'apparaît **ni** dans cette alerte **ni** dans les états `*_sensor_problem`. Détails firmware : [`docs/subsystems/sensors.md`](subsystems/sensors.md#détection-capteur-figé--feature-022).

## Topics et entités ajoutés en feature-050 (complétude MQTT/HA, v2.14.0)

Issus d'un audit de couverture web/API vs MQTT/HA (périmètre « rentable »). Trois compléments : cumuls journaliers exposés, volumes quotidiens programmés commandables, bouton redémarrage.

### Cumuls journaliers injectés (P1)

| Topic | Description | Retain | Auto-discovery HA |
|---|---|---|---|
| `{base}/ph_daily_ml` | Cumul journalier injecté pH en mL (`safetyLimits.dailyPhInjectedMl`), publié au cycle 10 s avec dédup, retombe à 0 à minuit | true | `sensor` « Dosage pH aujourd'hui » — `unique_id: poolcontroller_ph_daily_ml`, `unit: mL`, `state_class: measurement` |
| `{base}/orp_daily_ml` | Cumul journalier injecté chlore en mL (`safetyLimits.dailyOrpInjectedMl`), idem | true | `sensor` « Dosage Chlore aujourd'hui » — `unique_id: poolcontroller_orp_daily_ml`, `unit: mL`, `state_class: measurement` |

Complètent les `binary_sensor` « Limite Journalière pH/Chlore » existants (état atteint/non atteint) par la valeur numérique du cumul.

### Volume quotidien programmé commandable (P2)

Les topics d'état `{base}/ph_daily_target_ml` / `{base}/orp_daily_target_ml` (mode Programmée) deviennent commandables via `.../set` + 2 entités HA `number`.

| Entité | Type | `state_topic` | `command_topic` | `unique_id` | Détails |
|---|---|---|---|---|---|
| Volume quotidien pH | `number` | `{base}/ph_daily_target_ml` | `{base}/ph_daily_target_ml/set` | `poolcontroller_ph_daily_target` | min 0 / max 2000 / step 10, `unit: mL` |
| Volume quotidien Chlore | `number` | `{base}/orp_daily_target_ml` | `{base}/orp_daily_target_ml/set` | `poolcontroller_orp_daily_target` | min 0 / max 2000 / step 10, `unit: mL` |

Validation du handler (`drainCommandQueue`, sous `configMutex`) : payload non numérique → ignoré + `warning` ; négatif → clampé à 0 ; **valeur strictement supérieure à la limite journalière VIVE (`maxPhMlPerDay` / `maxChlorineMlPerDay`) lue au moment du drain → refusée** + `warning` + resync HA sur la valeur réelle (condition posée par `pool-chemistry`). Persistance NVS **si changement réel**, republication immédiate, log `info` « ... (MQTT) ». La borne discovery (2000 mL) est indicative ; la limite vive reste le garde-fou effectif.

### Bouton Redémarrer (P3)

| Topic | Description | Retain | Auto-discovery HA |
|---|---|---|---|
| `{base}/reboot/set` | Tout payload accepté (le bouton HA envoie `PRESS`). Redémarrage **différé propre** : flag consommé en tête de `drainCommandQueue()` au prochain tour de loop, après `kRestartApModeDelayMs`, puis `shutdownForRestart()` (flush `status=offline`, ADR-0011) + `ESP.restart()` | non | `button` « Redémarrer » — `unique_id: poolcontroller_reboot`, `device_class: restart` |

Jamais de `ESP.restart()` direct au moment du drain — même séquence que la route `POST /reboot`.

---

## Topics et entités ajoutés en feature-051 (heures de filtration éditables, v2.16.0)

Expose les heures du créneau de filtration en entités HA `text` **éditables** (composant `text/`), complétant le select « Mode Filtration ».

| Entité | Type | `state_topic` | `command_topic` | `unique_id` | Détails |
|---|---|---|---|---|---|
| Filtration début | `text` | `{base}/filtration_start` | `{base}/filtration_start/set` | `poolcontroller_filtration_start` | `pattern` `^([01][0-9]|2[0-3]):[0-5][0-9]$`, min 5 / max 5, `icon: mdi:clock-start` |
| Filtration fin | `text` | `{base}/filtration_end` | `{base}/filtration_end/set` | `poolcontroller_filtration_end` | idem, `icon: mdi:clock-end` |

Les états `{base}/filtration_start` / `{base}/filtration_end` (retain) sont publiés par `publishFiltrationState()` (valeurs `filtrationCfg.start` / `.end`) — au boot lors de la (re)connexion, à chaque changement, et au cycle périodique de `publishAllStatesInternal()`.

**Sémantique** (identique à l'UI web) : les heures ont un effet réel en mode **Programmation** (`manual`). En mode **Auto**, elles sont recalculées par la température au prochain `filtration.update()` → une saisie HA en mode auto est écrasée et l'état republié montre la valeur recalculée (consultation, auto-corrigé). Le `pattern` de la discovery valide le format côté HA ; le handler revalide `HH:MM` via `timeStringToMinutes` (défense en profondeur). **Aucun chemin de dosage touché** : le dosage teste l'état live `filtration.isRunning()`, pas le planning.

---

## Topics et entités ajoutés en feature-052 (planning éclairage HA, v2.17.0)

Miroir de la feature-051 pour l'éclairage : expose le planning horaire (activation + heures) en entités HA éditables, complétant le switch « Éclairage Piscine » (contrôle manuel du relais, **inchangé**).

| Entité | Type | `state_topic` | `command_topic` | `unique_id` | Détails |
|---|---|---|---|---|---|
| Mode Éclairage | `select` | `{base}/lighting_schedule` | `{base}/lighting_schedule/set` | `poolcontroller_lighting_schedule` | Options **Programmation / Désactivé** ; templates ↔ `ON`/`OFF` sur le fil → booléen `lightingCfg.scheduleEnabled`. `switch` à l'origine (feature-052), migré en `select` en bug-ha-eclairage-select (v2.17.2) |
| Éclairage début | `text` | `{base}/lighting_start` | `{base}/lighting_start/set` | `poolcontroller_lighting_start` | `pattern` `^([01][0-9]|2[0-3]):[0-5][0-9]$`, min 5 / max 5, `icon: mdi:clock-start` |
| Éclairage fin | `text` | `{base}/lighting_end` | `{base}/lighting_end/set` | `poolcontroller_lighting_end` | idem, `icon: mdi:clock-end` |

Les états `{base}/lighting_schedule` / `{base}/lighting_start` / `{base}/lighting_end` (retain) sont publiés par `publishLightingState()` enrichie (valeurs `lightingCfg.scheduleEnabled` / `.startTime` / `.endTime`) — au boot lors de la (re)connexion, à chaque changement, et au cycle périodique de `publishAllStatesInternal()`.

**Choix booléen conservé** (cf. feature-028) : `scheduleEnabled` reste un booléen côté firmware et dans `/get-config` (`lighting_schedule_enabled`) ; l'exposition HA a d'abord été un `switch` (ON/OFF), migrée en `select` « Mode Éclairage » en v2.17.2 (le fil reste ON/OFF, voir la note ci-dessus). Un payload invalide (ni `ON` ni `OFF`, ou `HH:MM` mal formé) est ignoré + `warning` + resync HA sur la valeur réelle. Le broadcast WS config (bug-sync, v2.14.1) propage tout changement HA vers l'UI web sans rechargement. **Aucun chemin de dosage touché.**

---

## Topic et entité ajoutés en feature-053 (Mode Boost, v2.18.0)

Le **Mode Boost** est une surchloration temporaire du jour (filtration prolongée + cible ORP relevée), auto-expirant au prochain minuit local. Détails firmware : [`docs/subsystems/pump-controller.md`](subsystems/pump-controller.md#mode-boost-feature-053). Décision structurante : [ADR-0025](adr/0025-mode-boost.md).

| Entité | Type | `state_topic` | `command_topic` | `unique_id` | Détails |
|---|---|---|---|---|---|
| Boost | `switch` | `{base}/boost` | `{base}/boost/set` | `poolcontroller_boost` | `payload_on: ON`, `payload_off: OFF`, `icon: mdi:flash` |

L'état `{base}/boost` (retain) est publié à la (re)connexion, à chaque changement (activation / désactivation / expiration) et au cycle périodique de publication. Le switch retombe **automatiquement** sur `OFF` à minuit local sans commande HA (l'expiration côté firmware republie l'état).

**Activation refusée sans heure synchronisée** : si `{base}/boost/set` reçoit `ON` alors que l'horloge n'est pas synchronisée, la commande est **ignorée** (l'expiration à minuit serait incalculable) et l'état réel (`OFF`) est republié → le switch HA se resynchronise. Même politique de sécurité que la route HTTP `POST /boost/start` (`409 time_not_synced`, voir [API.md](API.md#post-booststart--write)).

> **Effet chlore gaté au mode ORP `automatic`** : le relèvement de la cible ORP et de la limite journalière chlore ne s'applique qu'en mode de régulation ORP `automatic`. En mode Manuel / Programmé, l'activation du Boost n'étend **que la filtration** (l'injection manuelle reste bornée à la limite normale). Voir [ADR-0025](adr/0025-mode-boost.md).

---

## Topics et entités ajoutés en feature-056 (Mode d'installation, v2.19.0)

Le **mode d'installation** décrit le câblage réel de l'installation (3 archétypes) et remplace les anciens `regulation_mode` / `filtration_enabled`. Détails firmware : [`docs/subsystems/filtration.md`](subsystems/filtration.md) et [`docs/subsystems/pump-controller.md`](subsystems/pump-controller.md). Décision structurante : [ADR-0026](adr/0026-mode-installation.md).

| Entité | Type | `state_topic` | `command_topic` | `unique_id` | Détails |
|---|---|---|---|---|---|
| Mode d'installation | `select` | `{base}/install_mode` | `{base}/install_mode/set` | `poolcontroller_install_mode` | `icon: mdi:pipe-valve`, options FR **PoolController pilote / Alimenté par filtration / Filtration externe** + templates (voir ci-dessous) |
| Signal filtration externe | `switch` | — (optimiste) | `{base}/filtration_external_state/set` | `poolcontroller_filtration_external` | `payload_on: ON`, `payload_off: OFF`, `optimistic: true` (pas de `state_topic`), `icon: mdi:water-sync` |

**Select « Mode d'installation » — libellés FR côté HA, protocole inchangé** : comme les autres selects (filtration, régulation), la traduction est purement côté HA via templates de la discovery. Le protocole sur le fil reste strictement `managed` / `powered` / `external`.

- `value_template` : `{{ {'managed':'PoolController pilote','powered':'Alimenté par filtration','external':'Filtration externe'}.get(value, value) }}`
- `command_template` : `{{ {'PoolController pilote':'managed','Alimenté par filtration':'powered','Filtration externe':'external'}[value] }}`

**Switch « Signal filtration externe » — optimiste** : il n'a **pas** de `state_topic` (`optimistic: true`) car le contrôleur ne republie pas cet état — c'est un **signal entrant** consommé par la garde « présence d'eau ». Une automation HA (ex. état d'un contacteur, d'une prise connectée) publie `ON`/`OFF` sur `{base}/filtration_external_state/set` ; le contrôleur applique le timeout de fraîcheur (180 s) et le fail-safe OFF. Utile **uniquement** en mode d'installation `external`.

---

## Exclusions volontaires (politique MQTT/HA)

Cette section documente ce qui **n'est délibérément PAS exposé** en MQTT / Home Assistant. C'est une **politique assumée**, pas un backlog : l'audit de couverture (feature-050) a tranché chaque cas ci-dessous. Une ré-exposition future doit être justifiée par un besoin constaté, pas par principe de complétude.

| Non exposé | Pourquoi |
|---|---|
| **Injections manuelles** (déclenchement direct d'un dosage pH/chlore) | Sécurité chimique : aucun dosage ne doit pouvoir être déclenché par une automatisation sans supervision humaine. Une injection reste une action locale (UI web / écran), sous présence de l'opérateur. |
| **Limites journalières / horaires de dosage** (configurables) | Ce sont des **garde-fous**, pas des préférences d'usage. Les rendre commandables à distance affaiblirait la barrière de sécurité qu'ils constituent (une automatisation HA pourrait relever le plafond avant de doser). Exposition écartée dès la feature-013. |
| **Calibration EZO pH/ORP** | Requiert la présence physique (solutions étalon, sonde plongée). Action non automatisable à distance. |
| **OTA / mise à jour firmware** | Flux supervisé interactivement, avec vérification CRC/signature. Pas de déclenchement fire-and-forget. |
| **Factory reset** | Action destructive irréversible (efface config/NVS). Jamais exposée à une automatisation. |
| **Wi-Fi (scan, connexion, changement)** | Configuration réseau sensible ; couper le Wi-Fi via MQTT couperait le canal MQTT lui-même. Présence physique ou UI locale. |
| **Authentification (token, mot de passe)** | Secret ; jamais transporté ni modifiable via MQTT. |
| **Pompes en mode test** | Actionnement direct des pompes pour maintenance — présence physique requise, potentiellement destructif (dosage à sec). |
| **Transients d'affichage** : délai de stabilisation restant, `inject_remaining`, **cause de blocage dosage** | États de transition à durée de vie très courte, pertinents seulement pour l'UI temps réel (WebSocket). La cause de blocage dosage a été explicitement écartée en feature-022, sur besoin constaté (bruit pour HA, pas de valeur d'automatisation). |
| **Historique** (brut / horaire / quotidien) | Home Assistant dispose de son propre recorder / long-term statistics qui agrège les `state_class: measurement` déjà publiés. Dupliquer l'historique firmware vers MQTT serait redondant. |

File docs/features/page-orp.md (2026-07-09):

# Page ORP — `/orp`

- **Fichier UI** : [`data/index.html`](../../data/index.html) (section `#view-orp`)
- **URL** : `http://poolcontroller.local/#/orp`

## Rôle

Point d'entrée unique pour **tout** ce qui concerne l'ORP (potentiel redox, piloté par injection de chlore liquide) : mesure, mode de régulation, injection manuelle, historique, calibration. Structure **symétrique** de la page [pH](page-ph.md).

## Structure

En mode nominal, quatre zones :

1. **Bloc Statistiques** (bandeau compact, sans titre) — valeur ORP **filtrée** courante en grand (mV) + **ligne brute discrète** « brut · médiane · maj » + **rangée de chips** : chip d'état filtre cliquable (cf. [Chip d'état filtre](#chip-détat-filtre-feature-025)) et **chip d'état de calibration** (cf. [Chip d'état de calibration](#chip-détat-de-calibration-feature-034)) + dosage du jour (barre de progression, borne `max_orp_ml_per_day`).
2. **Carte Régulation ORP** — sélecteur de mode : `Automatique`, `Programmée`, `Manuelle`. Sous-blocs :
   - **Automatique** : ORP cible (mV) + bouton Sauvegarder.
   - **Programmée** : volume quotidien de chlore en mL + bouton Sauvegarder. Depuis la v2.8.0 (feature-011) : ligne « **Débit calculé : X,X mL/min** » (`#orp_scheduled_flow_line` / `#orp_scheduled_flow_value`, alimentée par le champ WS `orp_scheduled_flow_ml_per_min` ; affiche « — » avec `title` « Hors plage de filtration ou données indisponibles » quand la valeur est `null`) + hint statique « Le volume non injecté avant minuit est perdu (pas de report au lendemain). ». Volontairement **pas** de « sur Y h restantes » côté client : l'horloge du navigateur peut différer de celle de l'ESP32, seul le débit (source firmware) est affiché.
   - **Manuelle** : bloc Injection manuelle.
3. **Carte Historique** — graphique uPlot (feature-043, ex-Chart.js), plages `Tout` / `30j` / `7j` / `24h`, zone ombrée 600–800 mV (`ORP_MIN`/`ORP_MAX`, app.js) indiquant la plage de désinfection.
4. **Carte Calibration** — **remplace** Régulation + Historique pendant une session. Écran **guidé par stepper** (feature-034), 1 seul point de calibration (architecture symétrique de la page pH) — voir [Workflow calibration](#workflow-calibration).

Le bloc Statistiques reste visible en permanence.
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

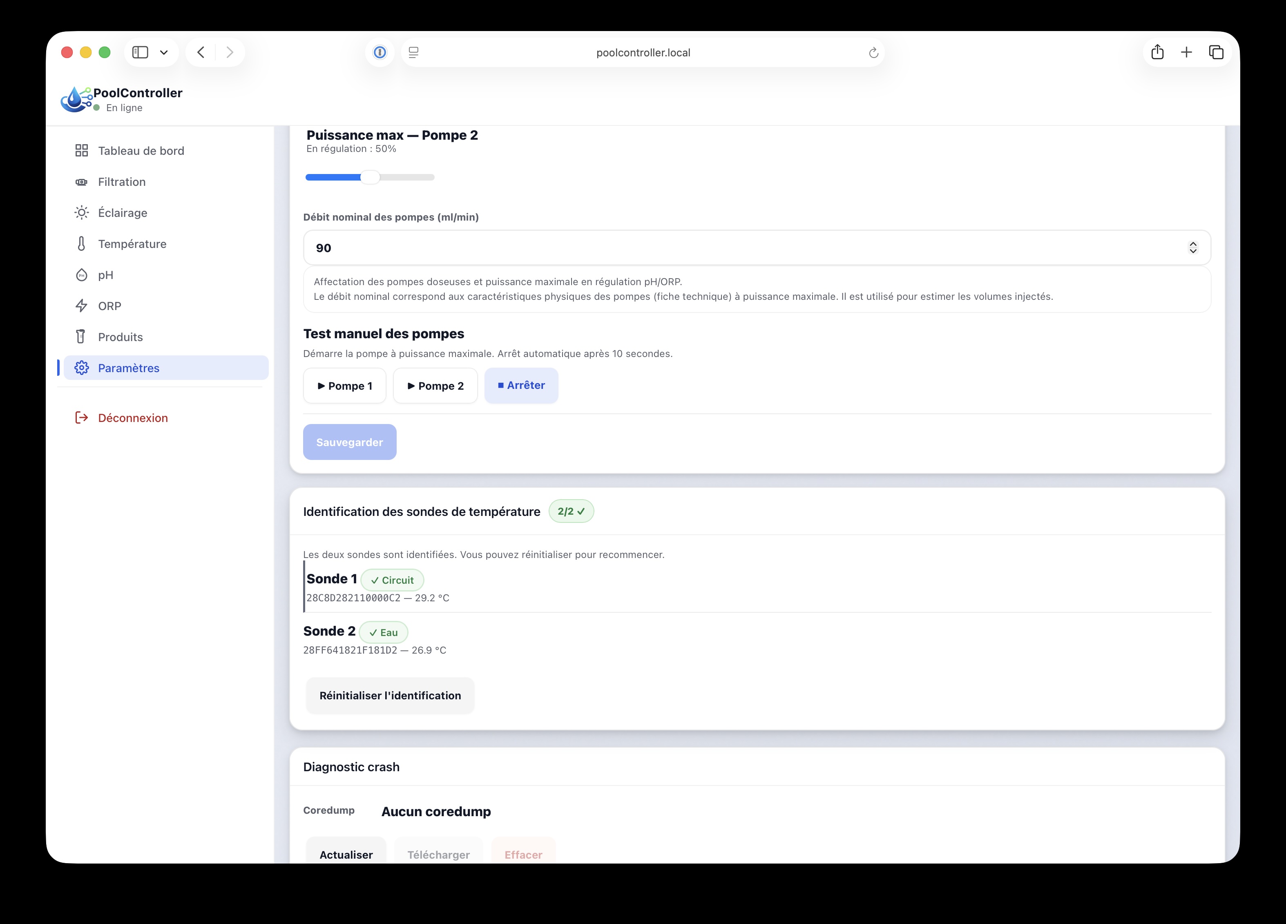
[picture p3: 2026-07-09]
screenshots/10_Paramètres_8_Avancé_2.jpg

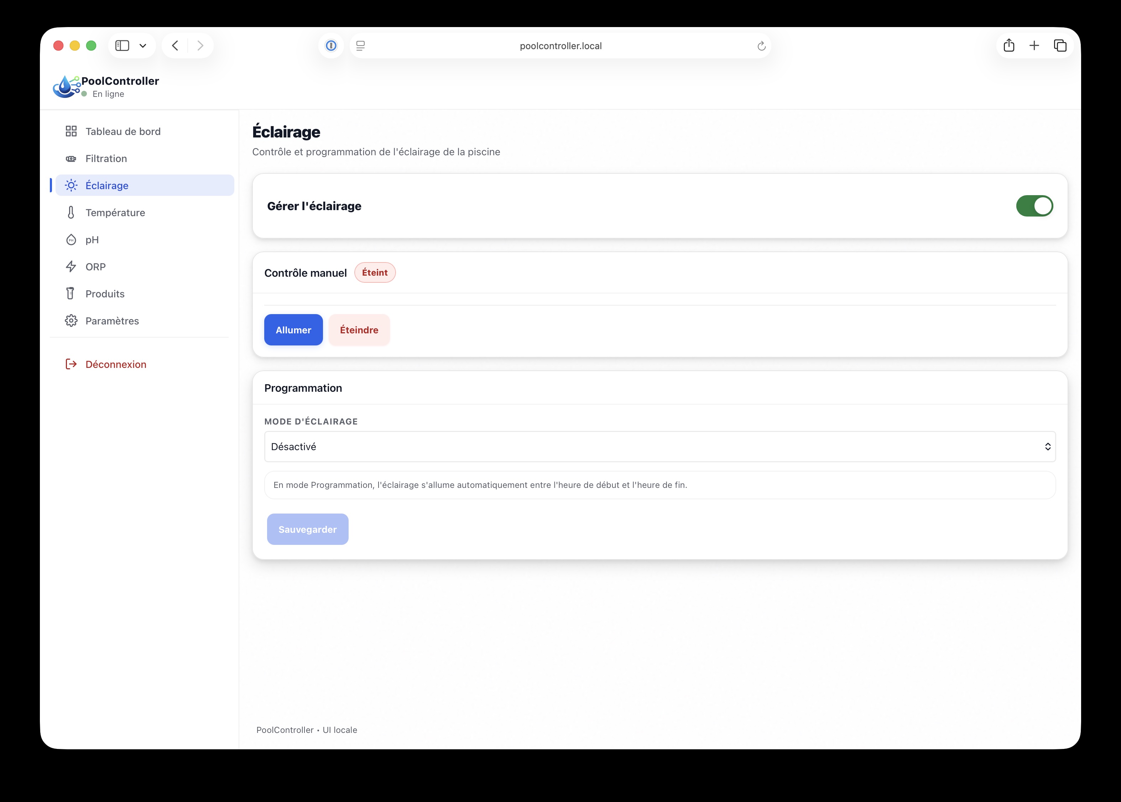
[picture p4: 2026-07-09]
screenshots/05_Eclairage.jpg

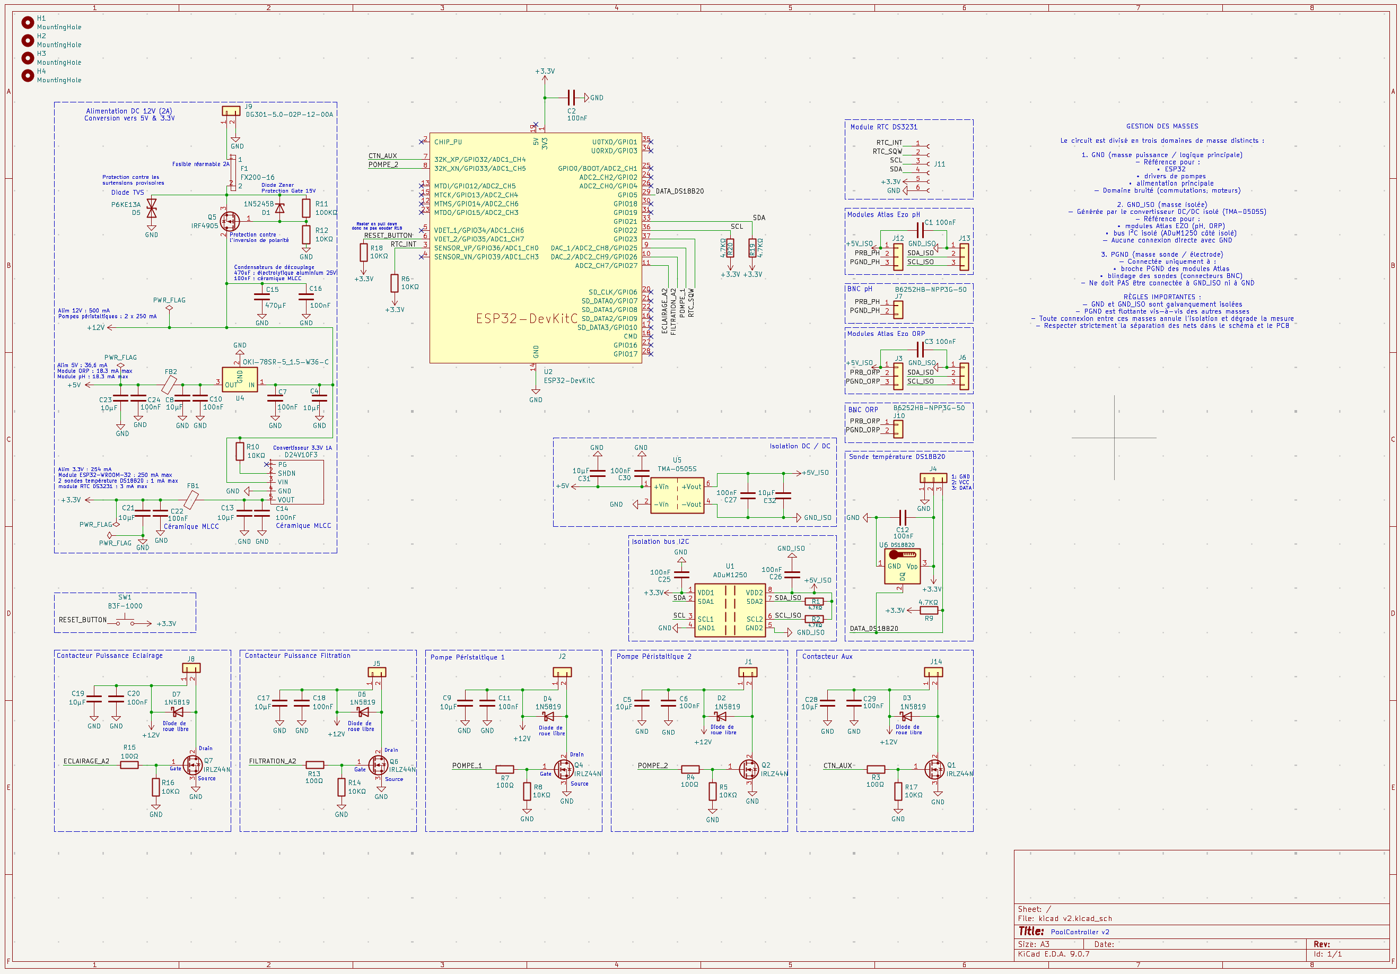
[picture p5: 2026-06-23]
screenshots/Schema.png

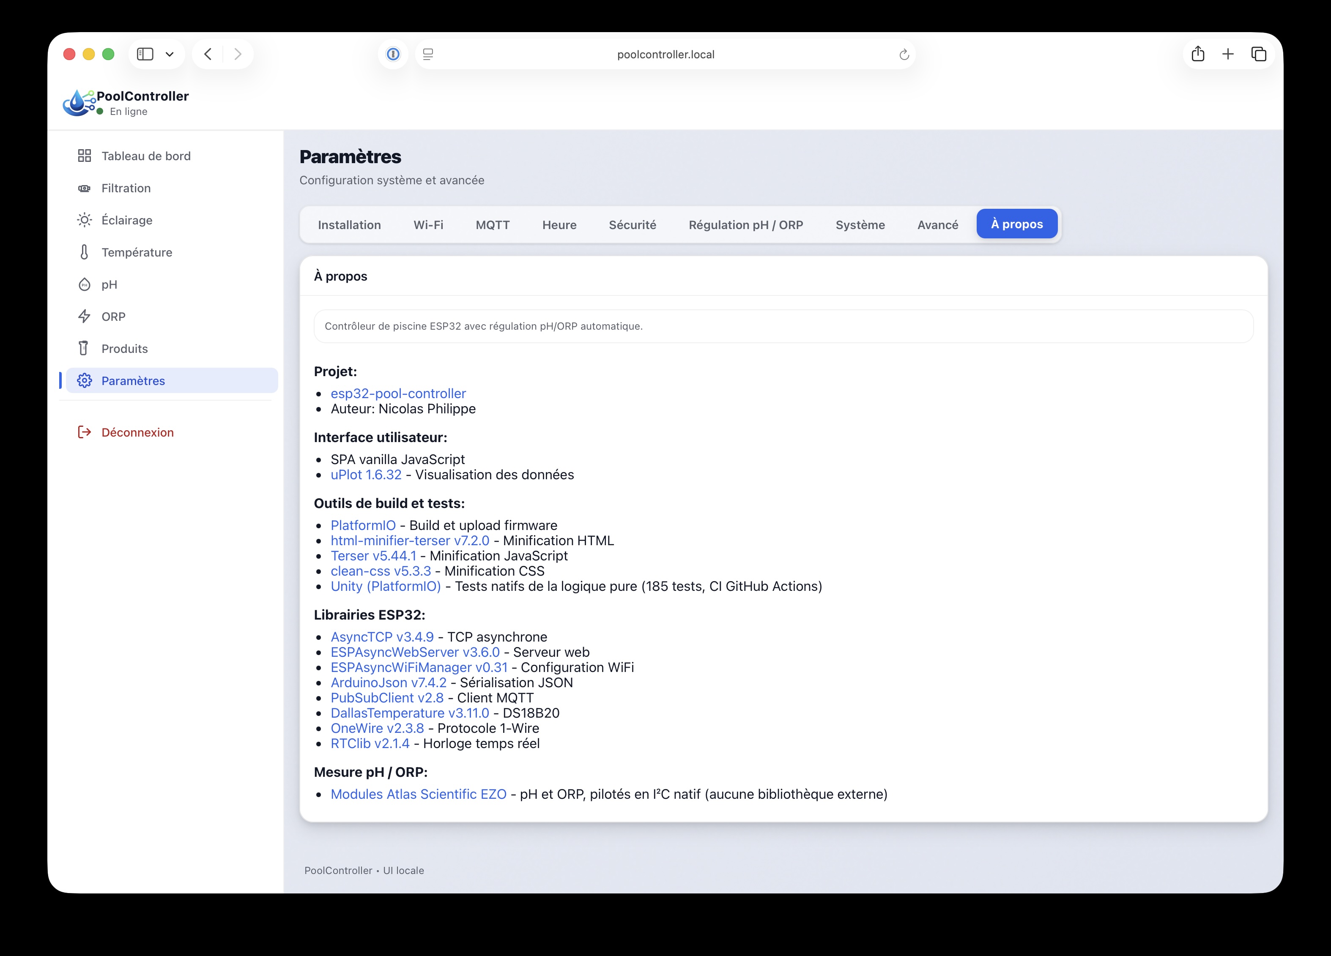
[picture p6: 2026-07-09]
screenshots/10_Paramètres_9_A_Propos.jpg

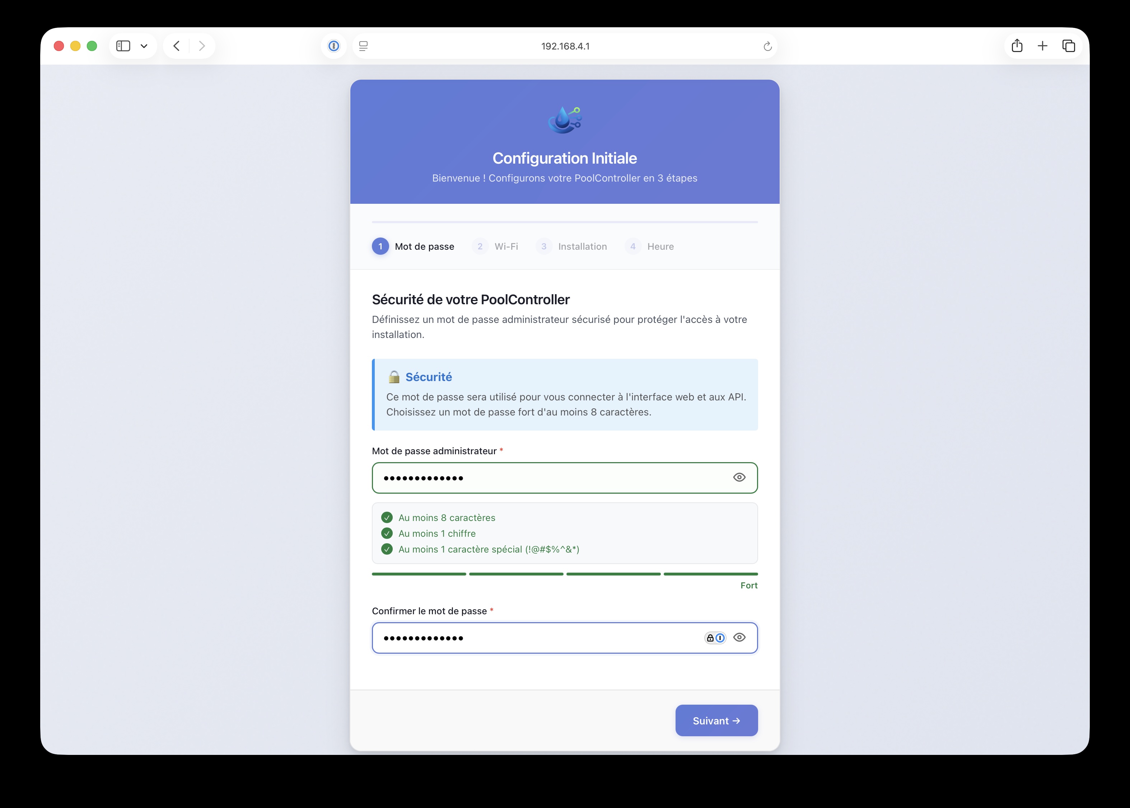
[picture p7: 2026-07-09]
screenshots/01_Assistant_Etape_1_Mot_de_passe.jpg

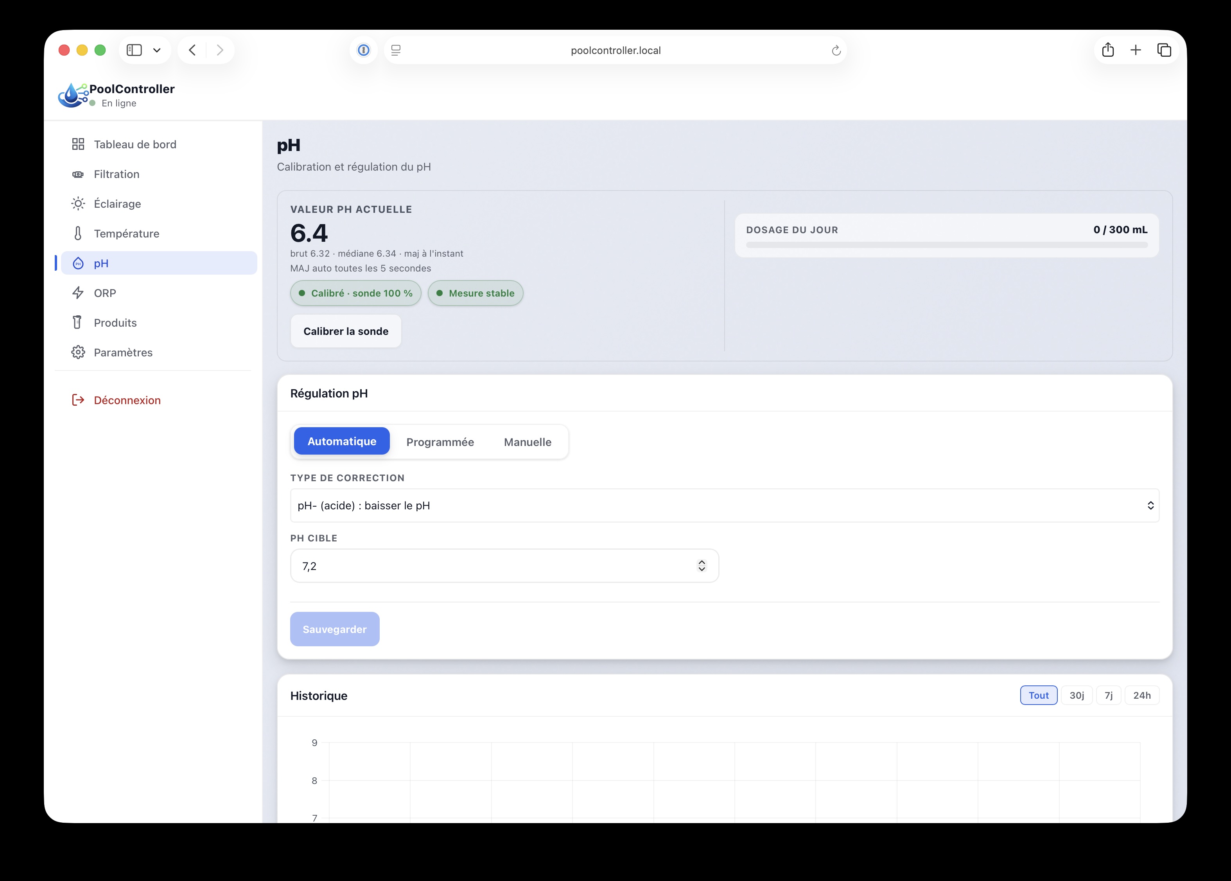
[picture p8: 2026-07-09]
screenshots/07_pH.jpg

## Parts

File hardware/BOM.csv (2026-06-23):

Reference | Qty | Value | Comment | Link
C1,C2,C3,C6,C7,C10,C11,C12,C14,C16,C18,C20,C22,C24,C25,C26,C27,C29,C30 | 19 | K104K10X7RF5UL2 | 100nF cŽramique X7R 10% 2.54mm | https://www.tme.eu/fr/details/k104k10x7rf5ul2/condensateurs-en-ceramique/vishay/
C4,C5,C8,C9,C13,C17,C19,C21,C23,C28,C31,C32 | 12 | FG20X7R1H106KRT06 | 10µF cŽramique mlcc X7R 10% 5.1mm | https://www.tme.eu/fr/details/fg20x7r1h106krt06/condensateurs-mlcc-tht/tdk/
C15 | 1 | ECA1EHG471B | 470µF Žlectrolytique 25V | https://www.tme.eu/fr/details/eca1ehg471b/condensateurs-electrolytiques-tht/panasonic/
D1 | 1 | 1N5245B | Diode: Zener; 0,5W; 15V | https://www.tme.eu/fr/details/1n5245btr/diodes-zener-tht/onsemi/
D2,D3,D4,D6,D7 | 5 | 1N5819 | Diode: redressement Schottky; THT; 40V; 1A; DO15; Ufmax: 900mV | https://www.tme.eu/fr/details/1n5819-dio/diodes-schottky-tht/diotec-semiconductor/1n5819/
D5 | 1 | P6KE13A |  | https://www.tme.eu/fr/details/p6ke13a-dio/diodes-unidirectionnelles-tvs-tht/diotec-semiconductor/p6ke13a/
F1 | 1 | 30R185UU | Fusible PPTC 30VDC courant maintien 1.85A THT 5.1mm | https://fr.farnell.com/littelfuse/30r185uu/polyfuse-ptc-radial-1-85a/dp/1822236
FB1,FB2 | 2 | BBPY00321611601Y00 |  | https://www.tme.eu/fr/details/bbpy00321611601y00/ferrites-perles/pulse/
J1,J2,J5,J8,J9,J14 | 6 | DG301-5.0-02P-12-00A |  | https://www.tme.eu/fr/details/dg301-5.0-2p12/blocs-de-bornes-dimpression/degson-electronics/dg301-5-0-02p-12-00a-h/
J3,J6,J11,J12,J13 | 5 | DS1002-03-1*20131 | Pour connecteur ESP32, module RTC, module pH, module ORPÉ | https://www.tme.eu/fr/details/zl307-1x20/batis-de-prises-et-prises-de-courant/connfly/ds1002-03-1-20131/
J4 | 1 | DG301-5.0-03P-12-00AH | Connecteur JST 3P
J7,J10 | 2 | B6252HB-NPP3G-50 |  | https://www.tme.eu/fr/details/b6252hb-npp3g-50/connecteurs-bnc/amphenol-rf/
Q1,Q2,Q4,Q6,Q7 | 5 | IRLZ44NPBF | Transistor: N-MOSFET; unipolaire; 55V; 41A; 83W; TO220AB | https://www.tme.eu/fr/details/irlz44npbf/transistors-tht-a-canal-n/infineon-technologies/
Q5 | 1 | IRF4905PBF | Transistor: P-MOSFET; unipolaire; -55V; -74A; 200W; TO220AB | https://www.tme.eu/fr/details/irf4905pbf/transistors-a-canal-p-tht/infineon-technologies/
R1,R2,R9,R19,R20 | 5 | 4.7KΩ | IdŽalement metal film 1% 0,25W. Si 1% pas disponible, 5% possible.
R3,R4,R7,R13,R15 | 5 | 100Ω | IdŽalement metal film 1% 0,25W. Si 1% pas disponible, 5% possible.
R5,R6,R8,R10,R12,R14,R16,R17,R18 | 9 | 10KΩ | IdŽalement metal film 1% 0,25W. Si 1% pas disponible, 5% possible.
R11 | 1 | 100KΩ | IdŽalement metal film 1% 0,25W. Si 1% pas disponible, 5% possible.
SW1 | 1 | B3F-1000 |  | https://www.tme.eu/fr/details/b3f-1000/micro-interrupteurs-tact/omron-electronic-components/
U1 | 1 | ADuM1250 |  | https://www.tme.eu/fr/details/adum1250arz/circuits-integres-autres-interfaces/analog-devices/
 | 1 | Adaptateur SOP8 vers DIP8 |  | https://www.gotronic.fr/art-adaptateur-so8-dil8-19701.htm
U2 | 1 | ESP32-DevKitC |  | https://fr.aliexpress.com/item/1005009089721727.html
U3 | 1 | D24V10F3 |  | https://www.tme.eu/fr/details/pololu-2830/onduleurs/pololu/3-3v-1a-step-down-d24v10f3/
U4 | 1 | OKI-78SR-5_1.5-W36-C
U5 | 1 | TMA-0505S |  | https://www.tme.eu/fr/details/tma0505s/convertisseurs-dc-dc/traco-power/tma-0505s/
U6 | 1 | DS18B20+ |  | https://www.tme.eu/fr/details/ds18b20+/transmetteurs-de-temperature/analog-devices-maxim-integrated/
 | 1 | Module Atlas EZO pH |  | https://www.digikey.fr/fr/products/detail/atlas-scientific/EZO-PH/16003108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
 | 1 | Module Atlas EZO ORP |  | https://www.digikey.fr/fr/products/detail/atlas-scientific/EZO-ORP/16003169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
 | 1 | Sonde pH connecteur BNC
 | 1 | Sonde ORP connecteur BNC
 | 1 | Module RTC DS3231 |  | https://fr.aliexpress.com/item/1005010435328928.html
 | 0 | module ADC ADS1115
 | 1 | Finder 22.32.0.012.4340 | Si contr™le filtration : Contacteur rail DIN 12V / 220V 25A
 | 1 | Finder 22.32.0.012.4340 | Si contr™le Žclairage : Contacteur rail DIN 12V / 220V 25A
 | 2 | Pompe PŽristaltique 12V 90ml/min 12V-S10B avec tuyau en BPT PharMed (plus simple ˆ trouver que tuyau Norprene ou Santopr ne) |  | https://fr.aliexpress.com/item/1005008568962671.html
 | 1 | Si tuyau pompe pas en Pharmed : tuyau Pharmed ˆ la coupe |  | https://fr.aliexpress.com/item/1005005939700189.html
 | 2 | Raccord ou clapet anti-retour en PVDF vers tuyau injection 4x6. Taille 1/8'' |  | https://fr.aliexpress.com/item/32721015040.html
 | 2 | Tuyau 4x6mm en PE pour raccorder tuyau pompe au bidon de produit |  | https://eau2.fr/tube-pe-chlore-et-ph/597-49-tube-pe-4x6mm-chlore-ph-piscine-pompe.html
 | 1 | Alimentation Rail DIN : Mean Well HDR-30-12 2A |  | https://www.amazon.fr/dp/B071KXJPYB?ref=ppx_yo2ov_dt_b_fed_asin_title
 | 2 | Clapet d'injection raccord 1/2'' Chlore ou pH |  | https://eau2.fr/analyseur-pieces-detachees-astralpool/404-clapet-ou-canne-injection-chlore-microdos-11100088-injection-ph-8432611951310.html
 | 1 | Collecteur piscine porte sonde diam tre 50 |  | https://jardiboutique.com/fr/regulateur-ph-rx/15015-collecteur-piscine-porte-sonde-transparent-diametre-50-jardiboutique-jb-so-1n500.html
 | 2 | Filtre aspiration pompe doseuse |  | https://eau2.fr/aspiration-du-chlore-liquide-et-ph-moins/733-crepine-aspiration-complete-4x6-100357-11100086-microdos-astralpool-8432611937871.html

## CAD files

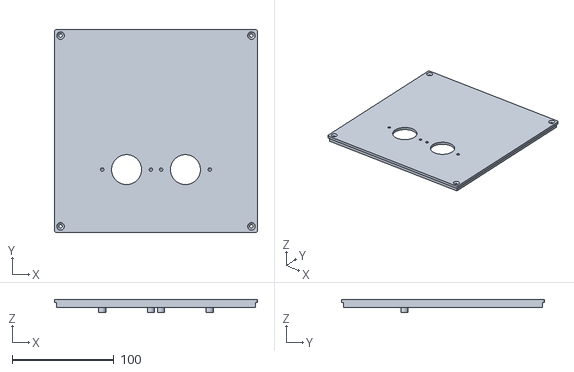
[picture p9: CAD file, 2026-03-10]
hardware/esp32-pool-controller v3-Couvercle.stl
200.0 x 200.0 x 13.0

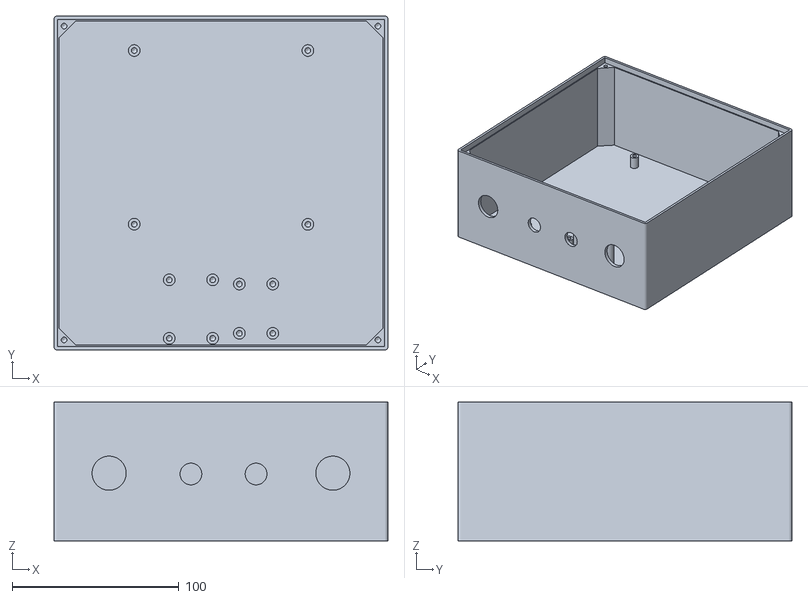
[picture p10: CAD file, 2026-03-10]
hardware/esp32-pool-controller v3-Boitier.stl
200.0 x 200.0 x 83.0

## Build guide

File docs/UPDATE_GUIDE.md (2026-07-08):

# Guide de Mise à Jour

> ⚠️ **Première installation obligatoire via USB** : le bootloader et la table de partitions personnalisée (`partitions.csv`) ne peuvent être flashés que via USB. Une fois cette installation initiale effectuée, toutes les mises à jour suivantes peuvent se faire en OTA (WiFi).

---

## Méthodes de mise à jour

| Méthode | Compile | USB requis | WiFi requis |
|---|:---:|:---:|:---:|
| `deploy.sh [firmware\|fs\|all]` | ✅ | ✅ | ❌ |
| `deploy.sh [ota-firmware\|ota-fs\|ota-all]` | ✅ | ❌ | ✅ |
| Interface web (OTA) | ❌ | ❌ | ✅ |
| Mise à jour automatique GitHub | ❌ | ❌ | ✅ |

---

## Mise à Jour via `deploy.sh` — compile + envoie en une commande

`deploy.sh` compile le firmware et le filesystem, puis envoie la mise à jour. Il supporte deux modes d'envoi.

### Mode USB — connexion série requise

Utile pour la première installation ou si l'ESP32 n'est pas accessible sur le réseau.

```bash
./deploy.sh all       # Firmware + filesystem
./deploy.sh firmware  # Firmware uniquement
./deploy.sh fs        # Filesystem uniquement
```

Le port série est configuré dans `platformio.ini` (`upload_port`). Adapter selon le système :
- macOS : `/dev/cu.usbserial-*`
- Linux : `/dev/ttyUSB0` ou `/dev/ttyACM0`
- Windows : `COM3`, `COM4`, etc.

### Mode OTA — WiFi, pas d'USB

```bash
./deploy.sh ota-all       # Firmware + filesystem via WiFi
./deploy.sh ota-firmware  # Firmware uniquement via WiFi
./deploy.sh ota-fs        # Filesystem uniquement via WiFi
```

Le script demande le mot de passe admin au lancement (ou via `POOL_PASSWORD=... ./deploy.sh ota-all`).

Par défaut, le script contacte l'ESP32 via mDNS (`poolcontroller.local`). Si le mDNS ne fonctionne pas sur votre réseau (certains CPL ou routeurs ne le relaient pas), utilisez directement l'adresse IP :

```bash
./ota_update.sh both 192.168.1.42 monmotdepasse
./ota_update.sh firmware 192.168.1.42 monmotdepasse
```

> L'adresse IP de l'ESP32 est visible dans **Paramètres > Système** ou dans les logs au démarrage (`INFO: IP: 192.168.x.x`).

---

## Mise à Jour via Interface Web — WiFi uniquement

1. Compiler les fichiers avec `./build_all.sh`
2. Accéder à http://poolcontroller.local
3. Aller dans **Paramètres > Système**
4. Sélectionner le fichier (`firmware.bin` ou `littlefs.bin`)
5. Cliquer sur **Mettre à jour**
6. Attendre le redémarrage automatique

> Si vous modifiez le code ET les fichiers web, faire 2 mises à jour séparées.

---

## Mise à Jour Automatique depuis GitHub — WiFi uniquement

L'interface web peut vérifier et télécharger automatiquement la dernière version depuis GitHub :

1. Accéder à **Paramètres > Système**
2. Cliquer sur **Vérifier les mises à jour** — consulte la dernière release GitHub
3. Si une nouvelle version est disponible, cliquer sur **Mettre à jour** — télécharge et installe automatiquement

> Le contrôleur se connecte directement à GitHub en HTTPS. Aucun USB, aucune manipulation de fichiers.

---

## Vérification d'intégrité SHA-256 — depuis v2.11.0

Depuis la v2.11.0, **toute image téléchargée depuis GitHub est vérifiée par empreinte SHA-256 avant d'être activée** ([ADR-0022](adr/0022-verification-integrite-ota.md)). L'empreinte de référence est le champ `digest` publié par GitHub pour chaque asset de release — aucune manipulation supplémentaire n'est requise pour un OTA nominal.

**Cas d'un échec de vérification (image tronquée ou corrompue, coupure WiFi pendant le téléchargement) :**

- **Firmware** : le flash est refusé **avant activation** — la carte reste sur la version actuelle, aucun redémarrage sur l'image suspecte. Message d'erreur explicite dans l'UI, log `CRITICAL` dans la page Logs. Relancer simplement l'installation.
- **Filesystem** : la partition de l'interface web contient une image suspecte — **pas de redémarrage automatique**, le firmware reste intact et bootable. **Réinstaller le filesystem** (relancer la mise à jour GitHub, ou `./deploy.sh ota-fs` / `./deploy.sh fs`). Tant que ce n'est pas fait, l'interface web peut être partiellement indisponible (le firmware et la régulation continuent de fonctionner).

**Cas d'une release sans empreinte (anciennes releases) :** le bouton **Installer** est **désactivé** avec le message « Cette release ne fournit pas d'empreinte d'intégrité — installation refusée (sécurité). » (comportement fail-closed voulu). Utiliser l'upload manuel ou `deploy.sh` pour installer une telle release.

**Upload manuel (`/update`, interface web ou curl) :** l'empreinte SHA-256 de l'image reçue est toujours calculée et loggée. Il est possible de fournir l'empreinte attendue via le champ POST optionnel `sha256` (voir [docs/API.md](API.md#post-update--critical)) — en cas de différence, le flash est refusé. Sans empreinte fournie, le flash reste autorisé (vous êtes physiquement présent). Un seul upload à la fois : un second upload lancé pendant qu'un premier est en cours est refusé (`409`).

---

## Notes de migration

### Mode d'installation (`install_mode`) — depuis v2.19.0 (2026-07-08)

La v2.19.0 fusionne les anciens réglages `regulation_mode` (Continu / Piloté) **et** « Gérer la filtration » (`filtration_enabled`) en un **mode d'installation** unique à 3 valeurs (`managed` / `powered` / `external`), exposé dans le nouvel onglet **Paramètres → Installation** et dans l'assistant de premier lancement. Décision structurante : [ADR-0026](adr/0026-mode-installation.md).

**Migration NVS automatique (one-shot, aucune action requise dans le cas nominal)** — à la première lecture de la config après mise à jour, si la clé `install_mode` est absente :

| Ancien `reg_mode` | Nouveau `install_mode` |
|---|---|
| `pilote` (ou toute valeur ≠ `continu`) | `managed` |
| `continu` | `powered` |

`external` n'est **jamais** produit par migration : c'est un mode nouveau, à choisir explicitement.

> ⚠️ **Cas de bord à vérifier — le relais de filtration peut changer de comportement.** La migration se base **uniquement** sur `reg_mode` et **ignore** l'ancien `filt_enabled`. Deux combinaisons héritées voient donc leur pilotage relais changer :
>
> | Ancienne config | Migre vers | Relais avant | Relais après |
> |-----------------|-----------|--------------|--------------|
> | `pilote` + « Gérer la filtration » **désactivé** | `managed` | inerte | **piloté** (GPIO 26) |
> | `continu` + « Gérer la filtration » **activé** | `powered` | piloté | **inerte** |
>
> C'est **conforme à l'intention** (la combinaison « alimenté par la filtration » + « PoolController pilote la filtration » est un non-sens matériel — un contrôleur alimenté par la pompe ne peut pas la couper sans se couper lui-même). **Après mise à jour, vérifier dans Paramètres → Installation que le mode choisi correspond bien à votre câblage réel**, et le corriger si besoin (notamment si vous utilisez une filtration tierce → choisir `external`).

**Mode `external` (filtration tierce)** : le contrôleur ne dose que si l'état réel de la filtration lui est signalé, via `POST /filtration/external-state?running=true|false` ou MQTT `{base}/filtration_external_state/set` (`ON`/`OFF`). **Sans signal depuis plus de 3 min** (ou au boot, aucun signal), l'eau est considérée absente et le dosage est **suspendu** (fail-safe). Prévoir une automatisation (Home Assistant, domotique) qui publie régulièrement cet état.

`regulation_mode` et `filtration_enabled` disparaissent de `/get-config`, `/save-config`, du WebSocket et de l'UART. Les automatisations qui les lisaient doivent basculer sur `install_mode`.

### Migration layout v3 → v4 (v2.13.0) — depuis 2026-07-06

⚠️ **Mise à jour par câble USB obligatoire, une seule fois.**

La version 2.13.0 change la **table de partitions** (layout v4, [ADR-0024](adr/0024-partitions-layout-v4.md)) : les slots firmware `app0`/`app1` passent de 1664 à **1792 KB** (+128 KB chacun), pris sur la partition `spiffs` qui passe de 576 à **320 KB** et se déplace à l'offset `0x390000` — rendu possible par la pré-compression gzip des assets (feature-048, payload FS 155 KB).

**Pourquoi l'USB est obligatoire :** l'OTA écrit uniquement à l'intérieur des partitions existantes — il ne peut **pas** modifier la table de partitions ni le bootloader. La migration se fait par câble série :

```bash
./deploy.sh all
```

Cette commande recompile firmware + filesystem, réécrit bootloader + table de partitions + firmware, puis flashe le FS au nouvel offset.

> ⛔ **Interdiction : ne JAMAIS pousser le firmware ou le filesystem v4 par OTA sur un appareil encore en table v3.** L'OTA ne change pas la table : elle resterait v3 même après « réussite » apparente. En particulier, une image FS construite pour 320 KB montée sur la partition `spiffs` de 576 KB présente des **métadonnées LittleFS discordantes** (taille d'image ≠ taille de partition) — interface web indisponible ou corrompue. La release 2.13.0 s'installe exclusivement par USB (`./deploy.sh all`).

> ⚠️ **NE PAS utiliser `./deploy.sh factory`** pour cette migration : il efface toute la flash, **y compris la NVS** (perte de la config, des calibrations, du WiFi, et régénération du mot de passe AP). `./deploy.sh all` suffit et préserve tout.

**Ce qui est préservé** (partitions inchangées en offset et en taille) :

- **Config NVS** : calibrations, identification des sondes, paramètres de régulation, WiFi, compteurs journaliers ;
- **Historique des mesures** (partition `history` à `0x3E0000`) ;
- **Coredump** (partition `coredump`).

**Vérifications post-flash** (Paramètres → Système → Infos système) :

- ligne **FS** : taille de partition **~320 KB** (occupation ≈48 %) ;
- **historique présent** : les graphiques du dashboard affichent les mesures antérieures à la migration ;
- les mises à jour OTA (firmware et filesystem) refonctionnent normalement avec les nouvelles bornes.

---

### Migration layout v2 → v3 (v2.4.0) — depuis 2026-07-04

⚠️ **Mise à jour par câble USB obligatoire, une seule fois.**

La version 2.4.0 change la **table de partitions** (layout v3, [ADR-0019](adr/0019-partition-app-1664k.md)) : les slots firmware `app0`/`app1` passent de 1536 à **1664 KB** (+128 KB chacun), pris sur la partition `spiffs` qui passe de 832 à **576 KB** et se déplace à l'offset `0x350000`.

**Pourquoi l'USB est obligatoire :** l'OTA écrit uniquement à l'intérieur des partitions existantes — il ne peut **pas** modifier la table de partitions ni le bootloader. Tenter un OTA firmware compilé pour le layout v3 sur un appareil encore en layout v2 est voué à l'échec. La migration se fait par câble série :

```bash
./deploy.sh all
```

Cette commande recompile firmware + filesystem, réécrit bootloader + table de partitions + firmware, puis flashe le FS au nouvel offset.

> ⚠️ **NE PAS utiliser `./deploy.sh factory`** pour cette migration : il efface toute la flash, **y compris la NVS** (perte de la config, des calibrations, du WiFi, et régénération du mot de passe AP). `./deploy.sh all` suffit et préserve tout.

**Ce qui est préservé** (partitions inchangées en offset et en taille) :

- **Config NVS** : calibrations, identification des sondes, paramètres de régulation, WiFi, compteurs journaliers ;
- **Historique des mesures** (partition `history` à `0x3E0000`) ;
- **Coredump** (partition `coredump`).

**Ce qui est réécrit :** le contenu de la partition `spiffs` (interface web) est re-flashé au nouvel offset — sans impact, il ne contient que l'UI.

**Après la migration :** les mises à jour OTA (firmware et filesystem) refonctionnent normalement avec les nouvelles bornes. Aucune autre action requise.

---

### Logs DEBUG désactivés par défaut — depuis 2026-04-30

**Aucune action utilisateur requise.**

Depuis cette version, les logs de niveau `DEBUG` sont **désactivés par défaut** côté firmware. L'objectif est d'alléger le buffer NVS (200 entrées max, partagé avec INFO/WARN/ERROR/CRITICAL) pendant le fonctionnement nominal et de faciliter la lecture de la page Logs.

**Comportement après mise à jour :**

- Default `false` après flash neuf ou OTA. Aucun nouveau log `DEBUG` n'apparaît dans la page Logs ni dans le buffer persistant.
- Les niveaux `INFO`, `WARN`, `ERROR`, `CRITICAL` ne sont **pas** affectés et continuent de s'afficher comme avant.

**Pour activer les logs DEBUG (par ex. en cas de diagnostic) :**

1. Aller dans **Paramètres → Avancé → card Logs**
2. Cocher le switch **« Logs DEBUG activés »** (placé immédiatement sous « Log des sondes »)
3. Cliquer **Enregistrer**

L'effet est immédiat (pas de redémarrage requis). La valeur est persistée en NVS sous la clé `debug_logs` et survit aux reboots. Pour désactiver à nouveau, décocher et enregistrer.

> Le filtre `DEBUG` de la barre de filtres de la page Logs reste indépendant : il pilote l'affichage navigateur uniquement. Quand le switch firmware est désactivé, ce filtre n'a plus rien à afficher (les entrées ne sont plus produites).

---

### Stabilité réseau MQTT — tâche dédiée — depuis 2026-04-27

**Aucune action utilisateur requise. Aucun changement de configuration.**

Avant cette version, une publication MQTT (par exemple un simple `OFF` de 33 octets sur un capteur de stock faible) pouvait bloquer la régulation pH/ORP plusieurs dizaines de secondes lorsque le réseau entre l'ESP32 et le routeur était lossy (typiquement sur un lien CPL/Powerline bruyant). Trois crashes `PANIC` watchdog ont été observés en production avec exactement cette signature.

Depuis cette version, **toute la communication MQTT s'exécute dans une tâche FreeRTOS dédiée** (`mqttTask`), totalement isolée de la régulation pH/ORP, de la filtration et du watchdog principal. Conséquences observables :

- **Aucun gel de la régulation** lors d'un broker injoignable ou d'une microcoupure réseau de plusieurs dizaines de secondes. Les compteurs `dailyPhInjectedMl`/`dailyOrpInjectedMl` continuent de s'incrémenter, les checks horaires/journaliers restent évalués, le PID continue de tourner.
- **Comportement utilisateur strictement identique** : mêmes topics MQTT, mêmes payloads, mêmes intervalles de publication, même auto-discovery Home Assistant. Aucune automation HA à reconfigurer.
- **`status=offline` publié immédiatement** lors d'un OTA / factory reset / redémarrage manuel, au lieu d'attendre les 90 s de timeout broker.
- **Coût RAM marginal** : ~16 KB de heap supplémentaire (8 KB stack `mqttTask` + 7 KB queues). RAM statique reste à 16.4 % (vs 16.4 % avant), bien sous le budget.

Détails techniques : voir [ADR-0011](adr/0011-mqtt-task-dediee.md) et [`docs/subsystems/mqtt-manager.md`](subsystems/mqtt-manager.md).

---

### Persistance des compteurs journaliers en NVS (`pool-daily`) — depuis 2026-04-24

**Contexte :** avant cette version, les compteurs `dailyPhInjectedMl` et `dailyOrpInjectedMl` étaient stockés uniquement en RAM. Tout reboot (watchdog, brownout, coupure secteur, OTA) les remettait silencieusement à zéro, contournant potentiellement la limite journalière de sécurité.

**Comportement après mise à jour :**

- Les compteurs sont persistés en NVS (namespace `pool-daily`, clés `ph_daily_ml`, `orp_daily_ml`, `daily_date`).
- Au boot, si la date locale (RTC/NTP) est la même que celle enregistrée en NVS, les compteurs sont restaurés.
- Si NTP/RTC n'est pas encore synchronisé au boot, les valeurs NVS sont restaurées de façon conservatrice (hypothèse même jour).

**Aucune migration nécessaire :** au premier boot après mise à jour, le namespace `pool-daily` n'existe pas encore — les compteurs démarrent à 0, ce qui est le comportement attendu.

**Reset journalier :** le reset est désormais aligné sur **minuit local** (heure RTC/NTP) et non sur une fenêtre glissante de 24 h depuis le dernier boot.

> ⚠️ **Recommandation :** configurer `stabilizationDelayMin ≥ 5 min` (Paramètres → Régulation) pour bénéficier d'une protection anti-double-quota au passage de minuit. Si ce paramètre est à `0`, le dosage peut reprendre immédiatement après le reset de minuit alors que la journée précédente venait d'atteindre son quota.

---

### Mode de régulation ORP (`orp_regulation_mode`) — depuis 2026-04-24

**Contexte :** avant cette version, la régulation ORP était pilotée par un booléen `orp_enabled`. Ce champ est remplacé par un enum `orp_regulation_mode` à trois valeurs (`automatic`, `scheduled`, `manual`).

**Migration automatique au premier démarrage :**

| Ancienne valeur | Nouvelle valeur |
|---|---|
| `orp_enabled = true` | `orp_regulation_mode = "automatic"` |
| `orp_enabled = false` | `orp_regulation_mode = "manual"` |

Aucune action requise. Le firmware effectue la migration à la première lecture de la NVS si la clé `orp_reg_mode` est absente.

**Compatibilité MQTT / Home Assistant :** le champ `orp_enabled` est conservé comme miroir dérivé (`true` si mode ≠ `manual`). Les automations Home Assistant utilisant ce champ continuent de fonctionner sans modification.

**Nouveau mode Programmée :** en mode `scheduled`, le firmware injecte un volume fixe de chlore par jour (`orp_daily_target_ml` mL), indépendamment de la valeur mesurée par le capteur ORP. Ce mode est adapté aux situations où le capteur ORP est en cours de remplacement ou de calibration. La limite journalière (`max_chlorine_ml_per_day`) reste appliquée.

**Nouveau champ `orp_daily_target_ml` :** initialisé à `0` (aucune injection programmée). À configurer dans la page ORP, onglet Programmée, si vous souhaitez utiliser ce mode.

---

### Mode de régulation pH (`ph_regulation_mode`) — depuis 2026-04-23

**Contexte :** avant cette version, la régulation pH était pilotée par un booléen `ph_enabled`. Ce champ est remplacé par un enum `ph_regulation_mode` à trois valeurs (`automatic`, `scheduled`, `manual`).

**Migration automatique au premier démarrage :**

| Ancienne valeur | Nouvelle valeur |
|---|---|
| `ph_enabled = true` | `ph_regulation_mode = "automatic"` |
| `ph_enabled = false` | `ph_regulation_mode = "manual"` |

Aucune action requise. Le firmware effectue la migration à la première lecture de la NVS si la clé `ph_reg_mode` est absente.

**Compatibilité MQTT / Home Assistant :** le champ `ph_enabled` est conservé comme miroir dérivé (`true` si mode ≠ `manual`). Les automations Home Assistant utilisant le switch `ph_enabled` continuent de fonctionner sans modification.

**Nouveau champ `ph_daily_target_ml` :** initialisé à `0` (aucune injection programmée). À configurer dans la page pH, onglet Programmée, si vous souhaitez utiliser ce mode.

---

## Dépannage

| Problème | Solution |
|---|---|
| Update Failed | Vérifier la connexion WiFi et réessayer |
| « Échec de la vérification d'intégrité » | Image tronquée/corrompue refusée par sécurité — relancer l'installation (si c'était le filesystem, le réinstaller) |
| Bouton Installer grisé « pas d'empreinte d'intégrité » | Release GitHub sans champ `digest` — installer via upload manuel ou `deploy.sh` |
| ESP32 ne redémarre pas | Utiliser le bouton RESET ou débrancher |
| Interface inaccessible | `./deploy.sh fs` (USB) |
| Authentification refusée | Vérifier le mot de passe ou utiliser `POOL_PASSWORD=...` |
| `poolcontroller.local` inaccessible | mDNS non supporté par le réseau — utiliser l'IP directe : `./ota_update.sh both 192.168.1.x motdepasse` |

## Migration v2.0.0 — PCB v2

⚠️ La version 2.0.0 cible exclusivement le **PCB v2** et n'est plus compatible avec le PCB v1 (mapping GPIO entièrement réassigné, voir [ADR-0012](adr/0012-mapping-gpio-pcb-v2.md) ; chaîne pH/ORP refondue sur Atlas EZO, voir [ADR-0014](adr/0014-migration-atlas-ezo.md)). **Ne pas flasher la 2.0.0 sur un PCB v1** — les sondes analogiques pH/ORP du v1 ne sont plus supportées par le firmware.

### Étape post-update 1 : identification des 2 sondes DS18B20 (feature-020)

Le PCB v2 ajoute une 2ᵉ sonde DS18B20 (eau piscine + circuit électronique). Après la première mise à jour vers 2.0.0, l'utilisateur doit identifier ces 2 sondes via :

**Paramètres → Avancé → card « Identification des sondes de température »**

Une **chip de notification ambré** apparaît sur le Dashboard tant que l'identification n'est pas faite. Workflow :

1. Tenir l'une des 2 sondes dans la main pendant ~30 secondes
2. Observer dans la card laquelle voit sa T° monter en temps réel
3. Cliquer le bouton « C'est l'eau de la piscine » ou « C'est le circuit interne » sur la sonde correspondante
4. La 2ᵉ sonde est automatiquement identifiée comme l'autre rôle (auto-permutation)
5. La card affiche « 2/2 sondes identifiées ✓ »

Tant que l'identification n'est pas faite, **`getTemperature()` continue de fonctionner** via fallback gracieux sur la 1ʳᵉ sonde détectée — pas d'interruption de service côté MQTT/HA. La compensation de température du pH (feature-021 Atlas EZO) sera plus précise une fois l'identification effectuée.

Si une sonde est remplacée physiquement (adresse ROM différente), un warning est loggé et l'utilisateur doit refaire l'identification pour la sonde manquante.

### Étape post-update 2 : recalibration EZO pH + ORP — OBLIGATOIRE (feature-021)

⚠️ La version 2.0.0 remplace la chaîne pH/ORP analogique (ADS1115 + DFRobot_PH) par les modules **Atlas Scientific EZO Embedded I²C** (pH 0x63, ORP 0x62). Voir [ADR-0014](adr/0014-migration-atlas-ezo.md). La calibration est désormais **mémorisée dans le module EZO**, pas en NVS ESP32 — aucune migration de données n'est possible depuis v1.x.

**Tant que la calibration n'est pas faite, la régulation pH/ORP automatique est inhibée** (10 garde-fous fail-closed dans `canDose()`, voir [docs/subsystems/pump-controller.md](subsystems/pump-controller.md)). En parallèle :

- Une alerte MQTT retain est publiée sur `pool/alerts/calibration_required`
- Une chip ambrée apparaît sur les cartes Régulation des pages pH et ORP
- Logger `critical` au boot et à chaque transition

#### Préparation

| Solution tampon requise | Quantité |
|---|---|
| pH 7.00 (point milieu) | ~50 mL pour rincer + plonger |
| pH 4.00 (point bas) | ~50 mL |
| Solution standard ORP (225 mV ou 470 mV — kit Atlas/Hanna) | ~50 mL |
| Eau distillée pour rinçage entre tampons | au besoin |

#### Workflow pH (2 points)

Pages **pH → carte Calibration**. Les 2 sous-blocs (point milieu + point bas) sont **parallèles** : ordre libre.

1. Rincer la sonde à l'eau distillée, sécher à la lingette douce.
2. Plonger dans le tampon **pH 7.00**, attendre 1 min.
3. Cliquer **« Calibrer le point 7.0 »** → toast info « Calibration en cours ».
4. Attendre que `phCalPoints` passe à `1` (toast succès, ~5 s).
5. Rincer, plonger dans le tampon **pH 4.00**, attendre 1 min.
6. Cliquer **« Calibrer le point 4.0 »** → `phCalPoints` passe à `2` → callout vert « Calibré 2 points ✓ ».

**Attendre 5 minutes** avant qu'un dosage automatique ne reprenne (stabilisation post-calibration `kStabilizationDurationPhMs`).

#### Workflow ORP (1 point)

Page **ORP → carte Calibration**.

1. Rincer la sonde, sécher.
2. Saisir la valeur de référence du tampon dans le champ « Référence (mV) » (par défaut 470).
3. Plonger dans la solution standard, attendre 1 min.
4. Cliquer **« Calibrer »** → `orpCalPoints` passe à `1` → callout vert.

**Attendre 3 minutes** avant qu'un dosage ORP automatique ne reprenne (stabilisation `kStabilizationDurationOrpMs`).

#### Vérifications

- L'alerte MQTT `pool/alerts/calibration_required` est clearée automatiquement (payload vide retain) une fois `phCalPoints >= 2` ET `orpCalPoints >= 1`.
- L'auto-discovery HA expose 2 nouveaux sensors (`Piscine pH Points Calibrés`, `Piscine ORP Points Calibrés`) — les ajouter en card pour visualiser l'état au quotidien.
- Plage de référence ORP acceptée : `0..1000` mV. Hors plage → HTTP 400.

> Si vous voulez **repartir d'une calibration vierge** (changement de sonde, recalibration complète), utiliser `POST /calibrate_clear {sensor:"ph"}` ou `{sensor:"orp"}` (exposé via UI sur les cartes Calibration). Le compteur `phCalPoints` / `orpCalPoints` repasse à `0`.

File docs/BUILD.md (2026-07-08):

# Guide de compilation et déploiement

Guide **opérationnel** : quelles commandes lancer pour compiler et déployer. Pour la structure des partitions et le pourquoi du layout courant (v4), voir [ADR-0024](adr/0024-partitions-layout-v4.md) et la source de vérité [`partitions.csv`](../partitions.csv).

## Compilation

### Firmware seul

```bash
pio run
```

Génère `.pio/build/esp32dev/firmware.bin`.

### Filesystem (LittleFS) seul

```bash
./build_fs.sh
```

Ce script :
1. Minifie HTML / CSS / JS **puis pré-compresse en gzip** (via `minify.js`, sortie dans `data-build/`, ignoré par git) ;
2. Construit `littlefs.bin` avec la **taille exacte de la partition `spiffs`** (327 680 octets = 320 KB, layout v4 — voir [ADR-0024](adr/0024-partitions-layout-v4.md)).

⚠️ **Ne pas utiliser `pio run -t buildfs`** : PlatformIO recalcule une taille incorrecte (128 KB), ce qui produit un `littlefs.bin` non conforme à la partition `spiffs`.

### Pré-compression gzip des assets (feature-048, v2.12.1)

Après minification, `minify.js` gzippe (zlib **niveau 9**) chaque fichier texte (`.js`, `.html`, `.css`) et n'écrit dans `data-build/` **que la variante `.gz`** (ex. `app.js` → `app.js.gz`). Les images et icônes sont copiées telles quelles, sans compression. ESPAsyncWebServer résout nativement `<fichier>.gz` et sert avec `Content-Encoding: gzip` — aucun changement firmware requis (voir [subsystems/web-server.md](subsystems/web-server.md#assets-statiques-pré-compressés-gzip)).

**Gain mesuré** : payload FS **443 → 155 KB** (occupation partition `spiffs` 78 % → 27 % du layout v3 de l'époque ; ≈48 % de la partition 320 KB du layout v4), chargement des pages ~4× plus rapide (le débit de l'ESP32 est le facteur limitant sur mobile). Ce gain est ce qui a rendu possible la réduction de `spiffs` à 320 KB au profit des slots app ([ADR-0024](adr/0024-partitions-layout-v4.md)).

Règles :
- ⚠️ **Ne jamais placer de fichier texte non compressé dans `data-build/`** : le dossier est entièrement régénéré par `minify.js` à chaque build — tout ajout d'asset texte se fait dans `data/`, le pipeline produit le `.gz`.
- **Caveat `curl`** : un `curl` brut sur un fichier statique reçoit l'octet-stream gzip (le navigateur, lui, décompresse de façon transparente). Utiliser `curl --compressed http://<ip>/app.js`. Les routes API/JSON ne sont **pas** concernées (réponses générées, jamais compressées).

### Tout en une commande

```bash
./build_all.sh
```

Enchaîne `pio run` puis `build_fs.sh`.

## Tests natifs (hors matériel)

L'environnement `native` (`platform = native` dans [`platformio.ini`](../platformio.ini)) compile et exécute la **logique pure** du firmware sur le PC, sans ESP32. Il ne se lance qu'explicitement :

```bash
pio test -e native
```

PlatformIO compile **un binaire par dossier `test/test_*`** ; `pio test -e native` couvre donc désormais **deux suites** :

| Dossier | Couvre | Source testée |
|---|---|---|
| `test/test_native_sensor_filter/` | filtrage médiane + EMA, warmup, rejets (feature-025) | `src/sensor_filter.cpp` |
| `test/test_native_dosing/` | décision de dosage (`evaluateDose`, hystérésis start/stop, non-régression pause-mélange) (feature-036) | `src/dosing_logic.cpp` |

Le `build_src_filter` de l'env `native` inclut les deux modules purs :

```ini
build_src_filter = +<sensor_filter.cpp> +<dosing_logic.cpp>
```

Ces deux sources ne dépendent **ni d'Arduino, ni de FreeRTOS, ni d'I²C** ; seul un shim minimal (`test/native_shim/`) fournit `NAN` / `isnan` / types entiers. Voir [ADR-0017](adr/0017-logique-metier-pure-humble-object-testabilite.md) pour la convention « logique pure séparée de la couche hardware ».

### Couverture de tests

Le script [`tools/coverage.sh`](../tools/coverage.sh) mesure la couverture des classes pures (`sensor_filter`, `dosing_logic`) via l'env dédié `native_coverage` (env `native` + instrumentation `--coverage`) et **gcovr** :

```bash
./tools/coverage.sh          # résumé console (lignes + branches) + rapport HTML
./tools/coverage.sh --open   # idem + ouvre coverage/index.html (macOS)
```

Prérequis : `gcovr` dans le venv PlatformIO (`~/.platformio/penv/bin/pip install gcovr`) et `/usr/bin/gcov` (Command Line Tools sur macOS — Apple LLVM, compatible). Le rapport HTML est généré dans `coverage/` (ignoré par git).

> **Portée** : seules les **classes pures** sont mesurées. La coquille `pump_controller.cpp` (collecte des globals + mapping énum→chaîne) est **exclue du build natif** — son équivalence est validée par revue, pas par couverture. Voir [ADR-0017](adr/0017-logique-metier-pure-humble-object-testabilite.md).

### Validation on-target (manuelle)

Les tests natifs ne couvrent que la **logique pure**. L'**intégration matériel + réseau** (I²C, PWM, RTC, LittleFS, WiFi, WebSocket, MQTT) et les **scénarios complets de régulation** se valident à la main sur la carte, via la check-list [`docs/test-on-target.md`](test-on-target.md) — à dérouler après un `./deploy.sh` touchant la régulation, la filtration, les capteurs ou la persistance.

## Upload / Déploiement

Le script [`deploy.sh`](../deploy.sh) est l'entrée unique pour tous les modes de déploiement. Lancer sans argument pour l'aide :

```bash
./deploy.sh
```

### Modes USB (câble série)

| Commande | Action |
|---|---|
| `./deploy.sh firmware` | Compile + upload firmware uniquement |
| `./deploy.sh fs` | Build + upload filesystem uniquement |
| `./deploy.sh all` *(défaut)* | Firmware + filesystem |
| `./deploy.sh factory` | Efface toute la flash, puis upload complet. **Génère un nouveau mot de passe WiFi AP** (NVS effacée) |

### Modes OTA (WiFi)

| Commande | Action |
|---|---|
| `./deploy.sh ota-firmware` | Firmware uniquement en OTA |
| `./deploy.sh ota-fs` | Filesystem uniquement en OTA |
| `./deploy.sh ota-all` | Firmware + filesystem en OTA |

Les modes OTA utilisent par défaut `poolcontroller.local` (mDNS). Pour cibler une IP directe :

```bash
./ota_update.sh both 192.168.1.42 monmotdepasse
```

Voir aussi [UPDATE_GUIDE.md](UPDATE_GUIDE.md) pour la procédure détaillée.

## Archivage automatique du firmware ELF

À chaque compilation réussie du firmware (commandes `firmware`, `all`, `factory`, `ota-firmware`, `ota-all`), `deploy.sh` archive le fichier `.pio/build/esp32dev/firmware.elf` dans le dossier `builds/` :

```
builds/firmware_20260427_143022.elf
builds/firmware_20260427_082810.elf
...
```

- **Rétention** : 10 archives au maximum — les plus anciennes sont supprimées automatiquement.
- **Dossier `builds/`** : exclu de git (`.gitignore`), local uniquement.
- **Pourquoi** : le décodage d'un coredump exige l'ELF **exact** qui tournait au moment du crash. Sans archive, si un reflash a eu lieu entre le crash et l'analyse, `esp_coredump` échoue avec une erreur SHA mismatch.

## Décodage d'un coredump

Workflow complet pour diagnostiquer un crash `PANIC` en production.

### 1. Récupérer le token d'authentification

Dans la console du navigateur (page ouverte sur l'interface du contrôleur) :

```javascript
sessionStorage.getItem('authToken')
```

Ou via l'API :

```bash
curl -s -X POST http://<ip>/auth/login \
  -H "Content-Type: application/json" \
  -d '{"password":"<mot-de-passe>"}' | jq -r '.token'
```

### 2. Télécharger le coredump

```bash
curl -H "X-Auth-Token: <token>" \
  http://<ip>/coredump/download -o coredump.bin
```

### 3. Décoder

```bash
./tools/decode_coredump.sh coredump.bin
```

Un deuxième argument optionnel permet de spécifier l'ELF à utiliser (utile si l'ELF courant ne correspond pas au firmware crashé) :

```bash
./tools/decode_coredump.sh coredump.bin builds/firmware_20260427_082810.elf
```

### 4. Récupérer d'un SHA mismatch

Si le coredump a été capturé avec un firmware différent de l'ELF courant, le script détecte le mismatch et affiche automatiquement les archives disponibles avec la commande exacte à relancer :

```
─────────────────────────────────────────────────────
Le coredump a été capturé avec un firmware différent.
SHA du coredump : 07b12255d2bba9c6

ELF archivés disponibles (du plus récent au plus ancien) :
  builds/firmware_20260427_143022.elf
  builds/firmware_20260427_082810.elf

Relancer avec l'ELF correspondant :
  ./tools/decode_coredump.sh coredump.bin builds/firmware_20260427_082810.elf
─────────────────────────────────────────────────────
```

Identifier l'archive dont la date/heure est antérieure au crash (visible dans les logs ou dans `reset_reason` WS), relancer avec cet ELF.

Voir aussi [ADR-0009](adr/0009-partition-coredump.md) pour la décision architecturale sur la partition `coredump`.

## Pièges connus

- **`pio run -t buildfs`** : ne génère pas un `littlefs.bin` de la bonne taille → utiliser `./build_fs.sh`.
- **`pio run -t uploadfs`** : reconstruit le filesystem à la mauvaise taille avant upload → utiliser `./deploy.sh fs` ou `./deploy.sh ota-fs`.
- **Partition `history` préservée** : l'upload filesystem OTA n'écrase que la partition `spiffs`. L'historique des mesures n'est **pas** perdu à la mise à jour UI (voir [ADR-0024](adr/0024-partitions-layout-v4.md) et [history.md](subsystems/history.md)).
- **Changement de table de partitions** : un nouveau layout (ex. v3 → v4 en v2.13.0) exige un **flash USB une fois** — l'OTA ne réécrit pas la table, et une image FS v4 (320 KB) ne doit **jamais** être poussée en OTA sur un appareil en table v3. Voir [UPDATE_GUIDE.md](UPDATE_GUIDE.md#migration-layout-v3--v4-v2130--depuis-2026-07-06).

## Dépendances PlatformIO

Liste des libs déclarées dans `platformio.ini` (`lib_deps`) — voir le fichier source pour les versions épinglées.

| Lib | Usage |
|-----|---|
| `AsyncTCP` | TCP asynchrone (base de ESPAsyncWebServer) |
| `ESPAsyncWebServer` | Serveur HTTP / WebSocket non bloquant |
| `ESPAsyncWiFiManager` | Wizard Wi-Fi premier boot |
| `ArduinoJson` (v7) | Sérialisation JSON |
| `PubSubClient` | Client MQTT |
| `OneWire` + `DallasTemperature` | Bus 1-Wire pour DS18B20 (eau + circuit) |
| `RTClib` | DS3231 RTC |

> **Libs supprimées en feature-021 (v2.0.0)** : `Adafruit ADS1X15` et `DFRobot_PH` ont été retirées des `lib_deps`. La chaîne pH/ORP est désormais entièrement portée par la mini-classe maison [`AtlasEzoSensor`](../src/atlas_ezo.h) qui pilote les modules Atlas EZO Embedded en I²C natif (`Wire`). Voir [ADR-0014](adr/0014-migration-atlas-ezo.md). Cette suppression libère ~12 KB de flash mais l'ajout de la queue + des routes de calibration consomme environ autant — le build tenait alors à 98.8 % flash (layout v1). Depuis le layout v4 ([ADR-0024](adr/0024-partitions-layout-v4.md), slots app 1792 KB), l'occupation firmware est redescendue à ~78,5 % (marge ~392 KB).

## Bibliothèque de graphiques uPlot (frontend)

Les 6 graphiques de l'UI (3 mini-charts du dashboard, 3 historiques détail pH / ORP / Température) sont rendus par **uPlot** depuis feature-043, qui remplace Chart.js v4.5.1 (`chart.umd.min.js`, ~208 KB, **supprimé**). Voir [ADR-0018](adr/0018-migration-uplot.md). Un 7ᵉ graphique (debug oscillation pH du panel Avancé) a été retiré en v2.5.0 (feature-045).

### Provenance et version

- Paquet npm **`uplot@1.6.32`** — version **FIGÉE**, récupérée une fois puis committée. Aucune dépendance npm au build ni au runtime (offline-first, pas de CDN).
- Fichiers committés dans `data/` : [`uPlot.iife.min.js`](../data/uPlot.iife.min.js) (~50 KB) et [`uPlot.min.css`](../data/uPlot.min.css) (~2 KB) — copies de `dist/uPlot.iife.min.js` et `dist/uPlot.min.css` du paquet.
- Chargés par [`data/index.html`](../data/index.html) via `<script>` + `<link>` — 100 % vanilla, **aucune étape de build ajoutée** au déploiement (cohérent [ADR-0006](adr/0006-frontend-vanilla-js.md)).

### Mise à jour manuelle (si nécessaire)

```bash
npm pack uplot@<version>     # télécharge uplot-<version>.tgz
tar -xzf uplot-<version>.tgz
cp package/dist/uPlot.iife.min.js package/dist/uPlot.min.css data/
```

Puis `./build_fs.sh` et **vérification de parité en navigateur** (aucun test automatisé frontend — dashboard, détail pH/ORP/Température, console sans erreur).

### Gain mesuré (feature-043)

Suppression de `chart.umd.min.js` : payload FS 601 054 → 449 177 octets (**−148,3 KB**), soit ≈ 449 KB — gain qui a rendu possible la réduction de la partition `spiffs` à 576 KB au profit des slots app (layout v3, [ADR-0019](adr/0019-partition-app-1664k.md)).

> **Options non reprises** : l'ancienne usine Chart.js `createLineChart` exposait des options **mortes** (`hideYAxis`, `showYAxisGrid`, `extraPlugins`, `annotation`, `backgroundColor`), inutilisées aux call-sites. L'usine uPlot ([`data/app.js`](../data/app.js)) ne les reprend **pas** — réduction de périmètre assumée (feature-043).

## Structure des fichiers de build

- [`partitions.csv`](../partitions.csv) — source de vérité pour les offsets et tailles.
- [`platformio.ini`](../platformio.ini) — plateforme, libs, flags de compilation.
- [`build_all.sh`](../build_all.sh) — firmware + filesystem en une commande.
- [`build_fs.sh`](../build_fs.sh) — filesystem uniquement (minification + taille correcte).
- [`minify.js`](../minify.js) — minification HTML / CSS / JS + pré-compression gzip niveau 9 (seule la variante `.gz` est embarquée).
- [`deploy.sh`](../deploy.sh) — wrapper unique pour upload USB ou OTA ; archive l'ELF à chaque build firmware.
- [`ota_update.sh`](../ota_update.sh) — utilitaire OTA bas niveau (appelé par `deploy.sh`).
- [`tools/decode_coredump.sh`](../tools/decode_coredump.sh) — décodage d'un coredump avec `xtensa-esp32-elf-gdb`.
- `data/` — sources UI (HTML / CSS / JS / images).
- `data-build/` — UI minifiée + gzippée (généré automatiquement, ignoré par git).
- `.pio/build/esp32dev/` — artéfacts de build (`firmware.bin`, `firmware.elf`, `littlefs.bin`).
- `builds/` — archives ELF horodatées (généré automatiquement, ignoré par git).

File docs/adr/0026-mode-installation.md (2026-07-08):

# ADR-0026 — Mode d'installation : 3 archétypes de câblage et résolution unique de la présence d'eau

- **Statut** : Accepté
- **Date** : 2026-07-08
- **Décideurs** : Nicolas Philippe (architect), pool-chemistry (GO pré + post)
- **Spec(s) liée(s)** : feature-056 (mode-installation) ; interagit avec feature-053/054/055 (Mode Boost — « filtration gérée » = `managed`)

## Contexte

Deux réglages dispersés et mal nommés décrivaient auparavant le câblage réel de l'installation :

- `regulationMode` (`"pilote"` / `"continu"`, sous l'onglet « Régulation pH/ORP ») — son **seul** effet était de court-circuiter la garde « présence d'eau » du dosage : en `continu`, on présumait de l'eau en permanence.
- `filtrationCfg.enabled` (« PoolController gère la filtration ») — pilotait le relais de filtration (GPIO 26) et la visibilité du widget/programmation.

L'installateur devait croiser ces deux réglages, et une combinaison n'avait aucun sens matériel (un contrôleur **alimenté par** le circuit de filtration ne peut pas **piloter** ce même circuit sans se couper l'alimentation). Surtout, un **troisième câblage réel restait dangereux** : une filtration pilotée par un système tiers (domotique, coffret existant). En `pilote`, le contrôleur ne dosait jamais ; en `continu`, il présumait de l'eau 24/7 alors que la filtration externe pouvait être coupée → **risque d'injection dans une eau stagnante**.

La garde « présence d'eau » est une **règle de sécurité chimique non négociable** du projet. Refondre sa source d'information est une décision structurante : elle contraint le dosage, la filtration, le contrat de config, le contrat MQTT et impose une migration NVS. Elle doit être formalisée et bornée.

## Décision

**Un enum unique `InstallMode` à 3 valeurs remplace `regulationMode` ET `filtrationCfg.enabled`.** Il décrit le câblage réel et pilote de façon cohérente la présence d'eau, le pilotage du relais et l'horizon de dosage. La sérialisation (config JSON / WS / MQTT / UART) est **stable et ne doit jamais être renumérotée** :

| `InstallMode` | Sérialisé | Câblage | Eau présente si… | Relais piloté par PC ? | Ancien équivalent |
|---|---|---|---|---|---|
| `ManagedFiltration` | `managed` | alim permanente + sortie 12 V → contacteur | PC commande la filtration ON (`filtration.isRunning()`) | **oui** (GPIO 26) | `pilote` + `enabled=true` |
| `PoweredByFiltration` | `powered` | alim = phase filtration | vrai en permanence (PC vivant ⟺ eau) | non | `continu` |
| `ExternalFiltration` | `external` | alim permanente, filtration tierce | dernier signal externe = ON **et** reçu il y a < `kExternalFiltrationStaleMs` (180 s) | non | *aucun (trou dangereux)* |

**La présence d'eau devient une fonction pure unique** `resolveWaterPresent(WaterPresenceInputs)` ([`src/dosing_logic.cpp`](../../src/dosing_logic.cpp), pattern Humble Object [ADR-0017](0017-logique-metier-pure-humble-object-testabilite.md)), **source unique** consommée par TOUS les sites de garde (régulation auto `canDose`, injection manuelle `evaluateManualInject`, monitor d'injection en cours). L'ordre des gardes de dosage est **inchangé** : seule la source du booléen « eau présente » est unifiée. La fonction est **fail-closed strict** (condition pool-chemistry #2 : doute = refus) :

- `managed` → `filtrationCommandedOn` ;
- `powered` → `true` ;
- `external` → `externalSignalKnown && (age <= externalStaleMs) && externalSignalOn` (la connaissance du signal est testée **avant** son âge : un signal jamais reçu au boot n'a pas d'âge signifiant → refus) ;
- mode inconnu → `false`.

**Signal de filtration externe (mode `external`)** : deux canaux équivalents, non bloquants, **sans persistance** (au boot, état inconnu → fail-safe OFF) :
- `POST /filtration/external-state?running=true|false` (auth WRITE, paramètre form OU query, **pas** de corps JSON) ;
- MQTT `{base}/filtration_external_state/set` (payload `ON`/`OFF`, switch optimiste HA « Signal filtration externe »).

L'état est stocké sous **portMUX** (`setExternalState` / `getExternalState`), sûr depuis un handler HTTP ou un callback MQTT async. Au-delà de 180 s sans nouveau signal → présence d'eau `false` (fail-safe), dosage suspendu.

**Effets dérivés du mode** :
- Relais de filtration piloté **uniquement** en `managed` ; retour anticipé dans `filtration.update()` sinon.
- Programmation filtration masquée en `powered` / `external`.
- Timer de stabilisation au démarrage filtration armé **uniquement** en `managed`.
- Horizon de répartition du mode scheduled = `remainingRangeMinutes(...)` en `managed`, `1440 − nowMin` sinon (borné par la garde présence d'eau).

**Migration NVS one-shot** : `migrateInstallMode(regMode, filtrationEnabled)` — `"continu"` → `powered`, sinon → `managed`. Écriture immédiate de la clé `install_mode`, l'ancien schéma n'est plus relu ensuite. `external` n'est **jamais** produit par migration (mode nouveau, choisi explicitement).

## Alternatives considérées

- **Option A (rejetée) — Ajouter une 3ᵉ valeur à `regulationMode`** (`pilote` / `continu` / `externe`). N'absorbe **pas** `filtrationCfg.enabled` : il resterait deux réglages à croiser, et la combinaison contradictoire (`continu` + filtration gérée) demeurerait exprimable — donc un état invalide persistant.
- **Option B (rejetée) — Conserver deux axes booléens** (« PC gère la filtration ? » × « eau présumée en permanence ? »). Les 2 axes offrent 4 combinaisons dont **une est un non-sens matériel** (alimenté par la filtration + PC pilote la filtration). Un état invalide représentable est une source de bug et de mauvaise configuration installateur ; l'enum à 3 valeurs le rend **inexprimable**.
- **Option C (retenue) — Enum unique à 3 archétypes de câblage.** Chaque valeur correspond à un câblage physique réel et déduit sans ambiguïté la présence d'eau, le pilotage relais et l'horizon. La 4ᵉ combinaison impossible est éliminée par construction.

## Conséquences

### Positives

- **Un seul réglage** décrit le câblage ; l'état invalide (alim-filtration + PC-pilote) est inexprimable.
- **Troisième câblage enfin sûr** : la filtration externe signalée dose **seulement** sur un signal récent (< 180 s), fail-safe OFF au boot et à l'expiration → plus de risque d'injection en eau stagnante.
- **Source unique de présence d'eau** (`resolveWaterPresent`), testable en natif, consommée à l'identique par tous les sites de garde → moins de risque de divergence entre chemins de dosage.
- **Contrat cohérent** config / WS / MQTT / UART (sérialisation `managed`/`powered`/`external`), select HA en libellés FR.

### Négatives / dette assumée

- **Migration ignore `filt_enabled`** : `migrateInstallMode` ne regarde que `reg_mode`. Deux combinaisons héritées changent donc de comportement relais :
  - `pilote` + `enabled=false` → `managed` : le relais devient **piloté** (avant : inerte) ;
  - `continu` + `enabled=true` → `powered` : le relais devient **inerte** (avant : piloté).
  Conforme à l'intention (la combinaison alim-filtration + PC-pilote est un non-sens matériel), mais à **signaler à l'installateur** (voir [UPDATE_GUIDE.md](../UPDATE_GUIDE.md)).
- **Le mode `external` dépend d'un signal tiers** : si l'automation HA/domotique cesse de publier, le dosage se suspend au bout de 180 s. C'est le comportement fail-safe voulu, mais il impose une intégration fiable côté tiers.

### Ce que ça verrouille

- La sérialisation `managed` / `powered` / `external` est **publique** (config JSON, WS, MQTT, UART) — ne jamais renuméroter l'enum ni renommer les chaînes.
- La présence d'eau passe **exclusivement** par `resolveWaterPresent()` : tout nouveau chemin de dosage doit consommer cette source unique (validation `pool-chemistry` + `code-reviewer`).
- Le contrat externe est verrouillé : route `POST /filtration/external-state` (param `running`), topics `{base}/install_mode` (+ `/set`) et `{base}/filtration_external_state/set`, champs WS `install_mode` / `water_present` / `filtration_state_source` / `filtration_state_stale` / `filtration_ext_*`.
- `regulation_mode` et `filtration_enabled` sont **retirés** de la config JSON / WS / UART.

## Références

- Code : [`src/dosing_logic.h`](../../src/dosing_logic.h) / [`src/dosing_logic.cpp`](../../src/dosing_logic.cpp) (`InstallMode`, `resolveWaterPresent`, `migrateInstallMode`), [`src/config.h`](../../src/config.h) / [`src/config.cpp`](../../src/config.cpp) (`installMode`, migration NVS, `installModeToString`/`installModeFromString`), [`src/filtration.h`](../../src/filtration.h) / [`src/filtration.cpp`](../../src/filtration.cpp) (`setExternalState`/`getExternalState`/`resolveWaterPresence`, relais conditionné), [`src/pump_controller.cpp`](../../src/pump_controller.cpp) (gardes présence d'eau + horizon scheduled), [`src/web_routes_control.cpp`](../../src/web_routes_control.cpp) (`POST /filtration/external-state`), [`src/mqtt_manager.cpp`](../../src/mqtt_manager.cpp) (topics + discovery), [`src/ws_manager.cpp`](../../src/ws_manager.cpp), [`src/uart_commands.cpp`](../../src/uart_commands.cpp), [`src/constants.h`](../../src/constants.h) (`kExternalFiltrationStaleMs = 180000`)
- Spec : `specs/features/doing/feature-056-mode-installation.md`
- Docs : [API.md](../API.md), [MQTT.md](../MQTT.md), [UPDATE_GUIDE.md](../UPDATE_GUIDE.md), [subsystems/filtration.md](../subsystems/filtration.md), [subsystems/pump-controller.md](../subsystems/pump-controller.md), [subsystems/ws-manager.md](../subsystems/ws-manager.md), [subsystems/mqtt-manager.md](../subsystems/mqtt-manager.md), [features/page-settings.md](../features/page-settings.md), [features/page-filtration.md](../features/page-filtration.md)
- ADR liés : [ADR-0017](0017-logique-metier-pure-humble-object-testabilite.md) (logique pure Humble Object — patron de `resolveWaterPresent`), [ADR-0025](0025-mode-boost.md) (Mode Boost — « filtration prolongée » n'a d'effet qu'en `managed`), [ADR-0021](0021-repartition-scheduled.md) (horizon de répartition scheduled)

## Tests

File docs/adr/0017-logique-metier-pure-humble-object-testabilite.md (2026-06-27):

# ADR-0017 — Logique métier pure (Humble Object) séparée de la couche hardware pour testabilité native

- **Statut** : Accepté
- **Date** : 2026-06-27
- **Décideurs** : architect, pool-chemistry
- **Spec(s) liée(s)** : [feature-036](../../specs/features/done/feature-036-dosage-testable-decision-pure.md)

## Contexte

La décision de dosage (`canDose()` dans [`pump_controller.cpp`](../../src/pump_controller.cpp)) est la zone la plus sensible du firmware côté sécurité chimique : elle décide si une pompe doseuse peut injecter du pH-, du pH+ ou du chlore. Or elle n'avait **aucun test automatisé**.

`canDose()` lit directement une dizaine d'objets globaux (`sensors`, `filtration`, `mqttCfg`, `safetyLimits`, `millis()`, `esp_task_wdt_status()`, le ring buffer anti-rafale). Cette dépendance aux singletons concrets et à FreeRTOS/I²C rend tout test natif impossible sans shimmer toute la chaîne matérielle.

Le risque s'est matérialisé : le bug « pause mélange armée au démarrage » (v2.2.5) coupait l'injection auto après ~1 cycle de boucle (`minInjectionTimeMs` jamais respecté) et n'a été détecté qu'en test terrain. Un test unitaire de la décision l'aurait attrapé immédiatement.

Un précédent existe : `SensorFilter` (feature-025) est déjà un module **pur** sans Arduino, couvert par 17 tests natifs. Il faut décider **maintenant** si on généralise ce pattern à la décision de dosage — et plus largement à la logique de régulation — pour pouvoir l'étendre sans rediscussion lors des prochains refactors.

## Décision

La **logique métier sensible est extraite en modules purs** (pattern *Humble Object*), séparés de la couche hardware :

- Le module pur ([`src/dosing_logic.h`](../../src/dosing_logic.h) / [`src/dosing_logic.cpp`](../../src/dosing_logic.cpp)) **n'inclut ni `<Arduino.h>`, ni FreeRTOS, ni I²C, ni `<vector>`/`<FS.h>`, ni `String`**. Il n'utilise que les en-têtes C (`<stdint.h>`, `<math.h>`), donc compile en natif.
- Les **entrées** sont une **struct POD** (`DoseInputs`) ; la **sortie** est une struct (`DoseDecision`) portant un **énum** de cause (`DoseRefusal`), pas une chaîne.
- La **coquille hardware** (`canDose()` dans `pump_controller.cpp`) reste « humble » : elle **collecte** les valeurs depuis les globals, appelle `evaluateDose()`, puis **mappe l'énum → String française** en y réinjectant les valeurs runtime. Les effets de bord (log edge-triggered, exposition WebSocket de la cause) restent dans la coquille.
- Le **temps est injecté en paramètre** (`runTimeMs`, `usedMs`) pour rendre les seuils temporels (ex. `minInjectionTimeMs`) testables sans attendre le temps réel.
- L'extraction est un **characterization refactor** : aucun verdict, cause, seuil ni ordre d'évaluation ne change (équivalence stricte validée par `pool-chemistry`).
- Chaque module pur a sa **suite de tests native** dans un dossier `test/test_*` dédié (`pio test -e native` compile un binaire par dossier).

## Alternatives considérées

- **Mocker les singletons `sensors` / `filtration` / `mqttCfg`** (rejetée) — exigerait d'introduire des interfaces virtuelles ou des doubles de test pour des objets concrets fortement couplés au matériel I²C/FreeRTOS. Coût élevé, surface de mock large et fragile, risque de tester le mock plutôt que la logique. Le pattern Humble Object atteint le même but (logique testée) en déplaçant la logique plutôt qu'en simulant le matériel.
- **Cause de refus en `const char*` statique dans le module pur** (rejetée) — aurait gardé le texte FR dans la logique pure. Rejetée car (1) elle mélange présentation (chaîne utilisateur) et décision, (2) elle empêche de réinjecter les valeurs runtime (`cal=X requis=Y`, `mode=X`) qui n'existent qu'au moment de la collecte côté coquille, (3) elle imposerait `<string.h>`/formatage au module pur. L'**énum + formatage dans la coquille** sépare proprement décision et libellé.
- **Statu quo (aucun test, logique dans `pump_controller`)** (rejetée) — laisse la zone la plus critique du firmware sans filet, comme l'a montré le bug pause-mélange.

## Conséquences

### Positives

- La décision de dosage est **couverte par des tests natifs rapides** (sans matériel), exécutables en CI/dev : 21 tests Unity dont un **verrou de non-régression** du bug pause-mélange v2.2.5.
- **Séparation nette** décision (pure, déterministe, auditable) / collecte+présentation (coquille). La table de vérité des gardes est lisible d'un coup d'œil dans `dosing_logic.cpp`.
- **Convention réutilisable** : les futurs refactors de régulation (calcul d'erreur, hystérésis, anti-windup) suivent le même découpage pur/coquille.

### Négatives / dette assumée

- **Frontière à maintenir manuellement** : la coquille doit garder la collecte des `DoseInputs` synchronisée avec les globals, et le mapping énum → String synchronisé avec `DoseRefusal`. Un oubli de champ côté collecte ne serait pas attrapé par les tests purs (ils testent la décision, pas la collecte).
- **Léger éclatement** : une décision est désormais répartie sur deux fichiers (module pur + coquille).

### Ce que ça verrouille

- Toute évolution future de la **décision de dosage passe par `dosing_logic`** et doit conserver l'équivalence stricte (validation `pool-chemistry`).
- La **frontière String/POD** est posée : les libellés français restent côté coquille, jamais dans la logique pure.
- Les modules de logique pure restent **sans dépendance Arduino/FreeRTOS** (en-têtes C uniquement) pour rester compilables en natif.
- `pio test -e native` reste la porte d'entrée des tests : un nouveau module pur ajoute un dossier `test/test_*` + son entrée dans `build_src_filter`.

## Références

- Code : [`src/dosing_logic.h`](../../src/dosing_logic.h), [`src/dosing_logic.cpp`](../../src/dosing_logic.cpp), [`src/pump_controller.cpp`](../../src/pump_controller.cpp) (coquille `canDose`), [`src/sensor_filter.cpp`](../../src/sensor_filter.cpp) (précédent pur, feature-025)
- Tests : `test/test_native_dosing/`, `test/test_native_sensor_filter/`, [`platformio.ini`](../../platformio.ini) (env `native`)
- Spec : [`specs/features/done/feature-036-dosage-testable-decision-pure.md`](../../specs/features/done/feature-036-dosage-testable-decision-pure.md)
- Doc : [`docs/subsystems/pump-controller.md`](../subsystems/pump-controller.md), [`docs/BUILD.md`](../BUILD.md)
- Voir aussi : [ADR-0016](0016-regulation-p-temporisee-vs-pid.md) (régulation P temporisée, feature-025)

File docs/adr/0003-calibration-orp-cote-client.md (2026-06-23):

# ADR-0003 — Calibration ORP calculée côté client, pas par le firmware

> **Statut : Superseded by [ADR-0014](0014-migration-atlas-ezo.md)** (2026-05-06)
> Cette décision valait pour la chaîne analogique ADS1115 (formule `offset + slope`
> calculée côté navigateur, persistée via `POST /save-config`). La migration Atlas EZO
> a supprimé ce calcul : la calibration ORP se fait désormais **dans le module EZO**
> (commande `Cal,<reference>` envoyée par `POST /calibrate_orp`), le firmware ne calcule
> plus aucun `offset`/`slope` et les clés NVS `orp_cal_*` ont été retirées. Voir feature-021
> et [ADR-0014](0014-migration-atlas-ezo.md). Contenu ci-dessous conservé à titre historique.

- **Statut** : Superseded by [ADR-0014](0014-migration-atlas-ezo.md)
- **Date** : antérieur à 2026-04 (comportement déjà en place lors de la refonte de la page ORP)
- **Doc(s) liée(s)** : [page-orp.md](../features/page-orp.md), [sensors.md](../subsystems/sensors.md)

## Contexte

La calibration pH est prise en charge par la bibliothèque `DFRobot_PH` : elle expose des endpoints firmware (`/calibrate_ph_neutral`, `/calibrate_ph_acid`, `/clear_ph_calibration`) qui déclenchent une écriture EEPROM côté sonde.

La calibration ORP, elle, n'a pas de primitive équivalente : aucune librairie tiers ne la gère. Il fallait donc décider **où** faire le calcul `offset` (1 point) ou `offset + slope` (2 points).

## Décision

La calibration ORP est **calculée côté client** (navigateur) à partir :
- de la tension brute courante du capteur (champ WebSocket `orp_voltage_mv` ou équivalent),
- de la ou des valeurs de référence saisies par l'utilisateur (solution d'étalonnage).

Les résultats (`orp_calibration_offset`, `orp_calibration_slope`, `orp_calibration_date`, `orp_calibration_reference`) sont persistés via l'endpoint générique **`POST /save-config`**. Aucun endpoint firmware dédié.

Le firmware applique la formule `ORP_final = ORP_brut × slope + offset` à chaque lecture ([`sensors.cpp`](../../src/sensors.cpp)).

## Alternatives considérées

- **Endpoints firmware dédiés** (type `POST /calibrate_orp_point1`, rejeté) — surface API plus large, code C++ dupliquant une logique triviale (deux moyennes et une division), et surtout plus difficile à itérer côté UI (chaque changement de protocole nécessite un upload firmware + filesystem).
- **Calibration côté firmware déclenchée par une commande unique** (`POST /calibrate_orp?ref=470`, rejeté) — idem, et empêche de prévisualiser la valeur calculée avant persistance.

## Conséquences

### Positives
- Le protocole d'assistant (1 point, 2 points, étapes guidées) est **entièrement en JS** : itérations rapides, pas de rebuild firmware.
- Le firmware reste simple : il ne connaît que la formule finale, pas la procédure.
- L'utilisateur voit la valeur brute en temps réel pendant la calibration (via WebSocket) sans endpoint spécifique.

### Négatives / dette assumée
- Si le client perd la connexion en plein milieu du calcul, la calibration est perdue (pas de reprise côté firmware).
- Un client malveillant peut envoyer un couple `(offset, slope)` arbitraire via `POST /save-config` (auth CRITICAL requise toutefois).
- La formule de calibration est **implicite au protocole** : si le protocole change (ex. 3 points), il faut mettre à jour le JS **et** documenter le changement dans la spec.

### Ce que ça verrouille
- Le firmware ne peut pas rejeter une calibration invalide sur la base du protocole : il accepte tout couple `(offset, slope)` cohérent avec les types. La validation métier est côté client.

## Références

- Code : [`src/sensors.cpp`](../../src/sensors.cpp) application de `orpCalibrationOffset` et `orpCalibrationSlope`
- Code : [`src/config.h`](../../src/config.h) struct `MqttConfig` champs ORP calibration
- Doc UI ORP : [page-orp.md](../features/page-orp.md) — protocole de calibration côté client
- API : [`docs/API.md`](../API.md) — il n'y a **pas** d'endpoint `/calibrate_orp_*` (différence avec pH qui en a)

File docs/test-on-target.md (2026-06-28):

# Validation on-target — check-list manuelle

Ce document complète les **tests unitaires natifs** (`pio test -e native`, 118 tests, 100 % lignes sur la logique pure) en couvrant ce qu'ils ne peuvent **pas** atteindre : l'**intégration matériel + réseau** (I²C, PWM, RTC, LittleFS, WiFi, WebSocket, MQTT) et les **scénarios complets**.

> **Quand l'exécuter** : après chaque `./deploy.sh all` (ou `firmware`/`fs`) qui touche la régulation, la filtration, les capteurs, la persistance ou les contrats web/MQTT. Pas besoin de tout rejouer à chaque fois — cocher la section concernée par le changement + la section **Dosage** (sécurité) en cas de doute.

## Où observer
- **Journal système in-app** : interface web → Paramètres → carte **Logs** (bouton *Actualiser*). Active « Logs des sondes » / « Logs DEBUG » pour le détail.
- **Moniteur série** : `pio device monitor -b 115200`.
- **UI temps réel** : tableau de bord (badges, chips d'état) — alimenté par WebSocket.
- **MQTT** : un client MQTT (ou Home Assistant) abonné à `pool/#`.

Convention : `[ ]` à cocher, **gras** = message de log attendu (au mot près).

---

## 1. Démarrage & capteurs
- [ ] Boot sans crash ; log de version firmware = version attendue (`src/version.h`).
- [ ] Watchdog actif (pas de reset cyclique).
- [ ] pH / ORP / température affichés sur le tableau de bord, valeurs **plausibles** (pH ~6–8, ORP ~600–800 mV, temp cohérente).
- [ ] Chip d'état filtre = « Mesure stable » après le warmup (≈ 5 mesures).
- [ ] 2 sondes DS18B20 identifiées (eau + circuit) si applicable.
- [ ] Débrancher brièvement une sonde EZO → chip « EZO indisponible » ; rebrancher → retour normal.

## 2. Filtration (horaire)
- [ ] **Plage simple** (ex. 08:00–18:00) : filtration ON dans la plage, OFF hors plage.
- [ ] **Plage à cheval sur minuit** (ex. 22:00–06:00) : ON la nuit, OFF le jour. *(cas le plus piégeux — vérifie `isMinutesInRange` start>end)*
- [ ] **forceOn** pendant une plage OFF → filtration ON ; **forceOff** pendant une plage ON → OFF.
- [ ] Timeout des forçages : laisser un forçage actif > 4 h → log **« ForceOn expiré (timeout 4h) »** / retour mode normal.
- [ ] **Mode auto** : changer la température de référence → la plage se recalcule (durée ≈ temp/2, bornée 1 h–24 h), log **« Planning auto: …°C → HH:MM-HH:MM »**.
- [ ] Désactiver la filtration → relais OFF, carte dashboard filtration masquée.

## 3. Dosage pH / ORP automatique (sécurité — prioritaire)
> Cible pH > pH mesuré (pour pH+) ou < (pour pH-) ; filtration active.
- [ ] **Cycle complet** : log **« Démarrage dosage pH (auto): pH=… cible=… erreur=… »** PUIS, après ≥ 30 s, **« Arrêt dosage pH (auto): durée=≥30s vol≈…mL »**. *(valide minInjectionTimeMs + feature-037)*
- [ ] **Pause mélange** : juste après l'arrêt, log **« [Dosage pH] Refus : pause mélange en cours »** pendant 15 min (20 min pour ORP). *(valide le fix v2.2.5 : pause armée à l'arrêt, pas au démarrage)*
- [ ] **Proportionnalité** : grosse erreur (cible loin) → débit élevé (proche du max) ; petite erreur → débit moindre. *(feature-037)*
- [ ] **Garde présence d'eau** : couper la filtration en plein dosage → injection stoppée, log **« Refus : filtration arrêtée »** (sauf mode continu).
- [ ] **Garde calibration** : sonde non calibrée (pH < 2 points) → **« Refus : calibration insuffisante »**, pas d'injection.
- [ ] **Garde filtre** : capteur instable / filtre non prêt → **« Refus : filtre capteur non prêt »** ou **« capteur instable »**.
- [ ] **Anti-rafale** : provoquer plusieurs cycles rapprochés → au-delà de 6/min ou 20/15 min, refus anti-rafale. *(feature-039)*
- [ ] **Limite horaire** : atteindre la limite (déf. 5 min/h pH) → injection coupée, **« limite horaire atteinte »**.
- [ ] **Limite journalière** : vérifier le plafond (déf. 300 mL/j pH, 500 mL/j chlore) — quotas **non dépassés**.
- [ ] **pH+ vs pH-** : selon le type configuré, le sens de correction est correct (erreur = cible−pH en pH+, pH−cible en pH-).

## 4. Rollover journalier
- [ ] Au passage de **minuit (heure locale NTP)** : log **« Reset journalier (minuit local) — pH=…/… mL, ORP=…/… mL »** ; compteurs journaliers remis à 0. *(feature-039)*
- [ ] Sans NTP (RTC seul) : reset par fallback 24 h → **« Réinitialisation compteurs journaliers (fallback 24h) »**.

## 5. Calibration sondes
- [ ] Écran de calibration guidé accessible **dans tous les modes** (auto, programmé, manuel). *(feature-034)*
- [ ] Calibration pH (points 7.0 / 4.0) et ORP : détection de fin **robuste**, y compris en **recalibrant un point déjà calibré**.
- [ ] Après calibration réussie : **stabilisation post-cal** (dosage suspendu le temps prévu), chip de calibration mis à jour.
- [ ] Pendant une injection en cours, le bouton « Calibrer » est **désactivé**.

## 6. Éclairage
- [ ] Plage horaire (ex. 20:00–23:00) : ON le soir, OFF sinon.
- [ ] **Manuel ON/OFF** prioritaire sur l'horaire.
- [ ] Cas `start == end` configuré → éclairage **allumé toute la journée** (divergence voulue vs filtration). *(feature-040)*

## 7. Température (écran dédié)
- [ ] Valeur courante + chip de calibration affichés ; bouton « Calibrer la sonde ».
- [ ] Calibration par offset (température de référence connue → offset) ; chip passe à « Calibré · … ». *(feature-035)*
- [ ] Désactiver la sonde → carte dashboard masquée.

## 8. WebSocket / UI temps réel
- [ ] Tableau de bord se met à jour en direct (pH/ORP/temp, badges filtration/dosage) sans recharger.
- [ ] Badge « injection en cours » s'allume pendant le cycle pompe, s'éteint après.
- [ ] Chip d'état filtre exact (Stabilisation / Mesure stable / Pics rejetés / Capteur instable / EZO indisponible).
- [ ] `phDoseBlockedReason` / `orpDoseBlockedReason` reflètent la vraie cause de refus (modal détail du chip).
- [ ] Couper le WiFi puis le rétablir → la WS se reconnecte, données reprennent.

## 9. MQTT / Home Assistant
- [ ] Topics `pool/...` publiés (mesures, états).
- [ ] **Auto-discovery HA** : entités créées automatiquement (capteurs, switches).
- [ ] Une commande depuis HA (ex. forcer filtration) est prise en compte.
- [ ] Reconnexion MQTT après coupure réseau.

## 10. Persistance (survie au reboot)
- [ ] Modifier une config (cible pH, plage filtration, mode) → **rebooter** → la config est **conservée**.
- [ ] Compteurs journaliers de dosage **persistés** (NVS) : après reboot en cours de journée, le cumul n'est pas remis à 0 à tort.
- [ ] Historique : après quelques heures, les **moyennes horaires** apparaissent (consolidation) ; survit au reboot (LittleFS).

## 11. OTA
- [ ] `./deploy.sh ota-firmware` puis `ota-fs` : mise à jour réussie, reboot propre, version mise à jour.
- [ ] Pendant l'OTA, le dosage est suspendu (pas d'injection pendant le flash).

## 12. Robustesse / sécurité
- [ ] Perte NTP/RTC : la filtration **conserve son état** (pas de faux start/stop), dosage gardé par les sécurités.
- [ ] Bouton reset matériel : comportement attendu.
- [ ] Aucun reset watchdog en fonctionnement nominal prolongé.

---

## Lien avec les tests automatiques
| Niveau | Couvre | Statut |
|---|---|---|
| **Unitaire natif** (`pio test -e native`, CI) | logique pure : décision/PID/anti-rafale/rollover dosage, filtrage, horaires, agrégation | ✅ 100 % lignes, automatisé |
| **On-target** (ce document) | intégration matériel + réseau + scénarios complets | 🟡 manuel, à dérouler après deploy |

Les deux sont **complémentaires** : l'unitaire attrape les régressions de logique (cf. bug pause-mélange v2.2.5) ; l'on-target valide que la **coquille** (collecte des globals, I²C, PWM, persistance) câble correctement cette logique au matériel réel.

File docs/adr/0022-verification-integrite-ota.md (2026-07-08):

# ADR-0022 — Vérification d'intégrité OTA par SHA-256 comparé au digest de l'API GitHub

- **Statut** : Accepté
- **Date** : 2026-07-06
- **Décideurs** : architect + code-reviewer (Approved après 2 correctifs), feature-026
- **Spec(s) liée(s)** : feature-026 (vérification d'intégrité OTA)

## Contexte

La règle de sécurité absolue #6 du projet (« OTA : toujours vérifier la signature/CRC avant flash ») n'était **pas satisfaite** : l'OTA reposait uniquement sur la validation implicite de `Update.end(true)` (magic byte de l'image ESP32). Une image tronquée par une coupure réseau ou corrompue en transit pouvait être flashée — point le plus critique de la revue de code du 2026-06-20, avec risque de brique.

Contraintes :
- Trois chemins OTA distincts : téléchargement GitHub (`/download-update`), upload manuel (`/update`), push ArduinoOTA/espota ;
- Le flux **filesystem** GitHub est écrit via `esp_partition_write()`, **hors** de la classe `Update` — un mécanisme limité à `Update` ne le couvrirait pas ;
- Handler AsyncWebServer : calcul incrémental obligatoire (pas de passe finale bloquante > 50 ms) ;
- Offline first : pas de nouvelle dépendance cloud au-delà de la source de release déjà utilisée ;
- Budget RAM serré pendant l'OTA (TLS déjà actif).

Opportunité vérifiée pendant la conception : l'API GitHub `releases/latest` — déjà interrogée par `/check-update` — expose un champ **`digest`** (`"sha256:<64hex>"`) par asset. Sa présence a été **confirmée sur la release réelle v2.5.2** du projet.

## Décision

1. **SHA-256 incrémental** (mbedtls, accélération matérielle ESP32) via la classe `OtaStreamHasher` ([`src/ota_integrity.h`](../../src/ota_integrity.h)), alimentée chunk par chunk sur les trois flux (firmware GitHub, filesystem GitHub, upload manuel). Empreinte de référence : le champ `digest` des assets GitHub — **zéro changement du process de release**.
2. **Transit du digest par l'UI** : `/check-update` relaie les champs additifs `firmware_digest` / `filesystem_digest`, que `app.js` repasse en paramètre POST `digest=` à `/download-update`. Même modèle de menace que l'URL déjà relayée par le client : whitelist d'hôtes GitHub côté firmware + auth `CRITICAL` sur la route.
3. **Fail-closed strict sur le chemin GitHub** : digest absent → `400 integrity_digest_missing` (refus **avant** toute connexion) ; malformé → `400 integrity_digest_invalid` ; mismatch → firmware : `Update.abort()` avant tout `end()` (l'image n'est **jamais** activée), filesystem : `422` sans restart + remontage LittleFS best-effort (la partition FS est suspecte mais le firmware reste intact et bootable — re-tentative requise). L'UI désactive le bouton « Installer » si une release ne fournit pas de digest.
4. **Upload manuel `/update`** : empreinte SHA-256 **toujours calculée et loggée** (traçabilité), comparaison **optionnelle** via le paramètre POST `sha256` (l'utilisateur est physiquement présent — fail-open documenté, conforme AC2 « ou explicitement documenté ») ; paramètre fourni mais malformé ou mismatch → `Update.abort()`, flash refusé.
5. **ArduinoOTA/espota non modifié** : le protocole espota transmet déjà le MD5 de l'image, vérifié par la stack `Update`.
6. **Logique pure séparée** (`parseSha256Digest` / `sha256Equal` temps constant / `sha256ToHex`, [`src/ota_integrity_logic.h`](../../src/ota_integrity_logic.h), pattern [ADR-0017](0017-logique-metier-pure-humble-object-testabilite.md)) — 22 tests natifs.

## Alternatives considérées

- **MD5 via `Update.setMD5()`** (rejetée) — mécanisme confiné à la classe `Update` : ne couvre **pas** le flux filesystem GitHub écrit via `esp_partition_write()`. Aurait exigé un second mécanisme pour le FS, et MD5 n'est pas le format exposé par l'API GitHub.
- **Re-fetch de l'API GitHub côté firmware au moment du download** (rejetée) — éviterait le transit par l'UI mais double le pic RAM (session TLS + `getString()` de la réponse API pendant que la session TLS du download se prépare) pour un gain de sécurité marginal (l'URL transite déjà par l'UI, whitelist + auth identiques).
- **Signature cryptographique asymétrique** (écartée, hors périmètre) — protège aussi contre une compromission de la source, mais exige une gestion de clés et un changement du process de release ; feature ultérieure possible, explicitement hors périmètre de la spec.
- **Relecture de la flash après écriture** (rejetée) — vérifierait l'écriture physique, mais `Update.end(true)` et `esp_partition_write` remontent déjà les erreurs d'écriture ; redondant avec le hachage du flux, coût en temps de flash.

## Conséquences

### Positives
- Règle de sécurité #6 satisfaite sur les trois chemins OTA : image tronquée (coupure WiFi incluse) ou corrompue → refus **avant activation**, version courante conservée, log `CRITICAL`, message français distinct côté UI.
- Zéro changement du process de release : le digest est généré par GitHub.
- Logique de parse/comparaison testable en natif (22 tests), comparaison en temps constant.

### Négatives / dette assumée
- **Anciennes releases sans champ `digest`** : installation refusée par l'UI (bouton désactivé) — fail-closed assumé, contournable par upload manuel.
- **Usure flash sur digest fourni mais faux** : l'image est intégralement téléchargée et **écrite** avant le refus (la comparaison ne peut se faire qu'en fin de flux) — un cycle d'écriture de partition perdu par tentative, sans danger (partition inactive / FS re-flashable).
- Après un mismatch **filesystem**, la partition FS contient une image suspecte : l'UI peut être indisponible jusqu'à un nouvel OTA FS réussi (le firmware, lui, reste bootable).

### Ce que ça verrouille
- Le chemin GitHub est **fail-closed** : aucun téléchargement sans digest valide — assouplir exigerait un nouvel ADR.
- Le format d'empreinte est `sha256:<64hex>` (format API GitHub, `kOtaSha256Prefix`) ; en changer casse la chaîne UI → firmware.
- Toute évolution du parse/comparaison passe par la logique pure `ota_integrity_logic` (ADR-0017).
- Le firmware sur mismatch n'active **jamais** l'image (`Update.abort()` avant `end()`) ; le FS sur mismatch ne redémarre **jamais** automatiquement.

## Références

- Code : [`src/ota_integrity.h`](../../src/ota_integrity.h) / [`src/ota_integrity.cpp`](../../src/ota_integrity.cpp) (`OtaStreamHasher`), [`src/ota_integrity_logic.h`](../../src/ota_integrity_logic.h) / [`src/ota_integrity_logic.cpp`](../../src/ota_integrity_logic.cpp), [`src/web_routes_ota.cpp`](../../src/web_routes_ota.cpp), [`src/constants.h`](../../src/constants.h) (`kOtaSha256HexLen`, `kOtaSha256Prefix`), [`data/app.js`](../../data/app.js) (transit du digest, messages d'erreur)
- Tests : `test/test_native_ota_integrity/` (22 tests natifs)
- Spec : `specs/features/doing/feature-026-verification-integrite-ota.md`
- Doc : [docs/subsystems/ota-manager.md](../subsystems/ota-manager.md), [docs/API.md](../API.md#mises-à-jour-ota), [docs/UPDATE_GUIDE.md](../UPDATE_GUIDE.md)
- ADR liés : [ADR-0017](0017-logique-metier-pure-humble-object-testabilite.md) (logique pure)

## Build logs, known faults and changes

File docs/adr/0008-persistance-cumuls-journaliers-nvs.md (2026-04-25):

# ADR-0008 — Persistance NVS des cumuls journaliers + reset aligné minuit local

- **Statut** : Accepté
- **Date** : 2026-04-24 (CHANGELOG [Unreleased])
- **Doc(s) liée(s)** : [pump-controller.md](../subsystems/pump-controller.md), [page-ph.md](../features/page-ph.md), [page-orp.md](../features/page-orp.md)

## Contexte

Avant cette décision, les cumuls de produit chimique injecté sur la journée (`dailyPhInjectedMl`, `dailyOrpInjectedMl`) étaient **uniquement en RAM**. Deux failles :

1. **Un reboot remettait le cumul à zéro.** Un watchdog qui reset l'ESP32 en fin d'après-midi laissait tout l'après-midi disponible à re-consommer la limite journalière → risque de **double quota**, donc surdosage.
2. **Fenêtre « journalière » glissante sur 24 h**, pas alignée sur minuit local. Un utilisateur qui voyait « 280 mL sur 300 » à 22 h s'attendait à repartir à zéro à minuit. En pratique, le compteur ne redescendait qu'à 22 h le lendemain → comportement non intuitif, et incohérent avec la façon dont les docs / UI présentent la limite (« aujourd'hui »).

L'ORP et le pH sont tous deux concernés par ce risque, le pH encore plus critique (acide fort).

## Décision

Deux changements couplés :

1. **Persistance NVS** — les champs `dailyPhInjectedMl` et `dailyOrpInjectedMl` sont sauvegardés dans le namespace NVS `pool-daily`, avec la date locale `currentDayDate` (format `YYYYMMDD`). Au boot :
   - si la date locale est identique à celle persistée → les cumuls sont **restaurés** ;
   - si elle a changé → les cumuls sont **remis à zéro** (nouveau jour).
2. **Reset aligné sur minuit local** — plutôt qu'une fenêtre glissante de 24 h, le reset du cumul journalier est déclenché au passage de minuit dans le fuseau configuré (`timezoneId`). Le timer de stabilisation (`armStabilizationTimer`) est armé au passage de minuit pour éviter un démarrage d'injection dans la foulée du reset (mitigation double-quota si le firmware démarre une injection juste avant/après minuit).

La structure `SafetyLimits` ([`config.h`](../../src/config.h)) contient désormais `char currentDayDate[9]` pour tracer la date du dernier reset.

## Alternatives considérées

- **Garder la fenêtre glissante** (rejeté) — simple mais contre-intuitif, et ne résout pas la perte au reboot.
- **Reset UTC au lieu de local** (rejeté) — un utilisateur en Europe verrait son cumul repartir à 1 h ou 2 h du matin selon saison, aucune utilité.
- **Persistance sur LittleFS au lieu de NVS** (rejeté) — NVS est plus résistante aux coupures (wear leveling intégré), écriture plus rapide, mieux adaptée à un compteur mis à jour périodiquement.
- **Persistance à chaque injection** (rejeté) — use wear excessive de la flash. Flush périodique + flush sur bord descendant d'injection suffit.

## Conséquences

### Positives
- Le compteur journalier survit aux reboots (watchdog, OTA, coupure).
- Le reset à minuit local est aligné sur la mental map de l'utilisateur.
- La limite journalière redevient une vraie barrière sécuritaire, pas une suggestion effaçable par un reboot.

### Négatives / dette assumée
- Wear NVS accru : le flush se fait à un tempo modéré (voir `_lastDailySaveMs` dans [`pump_controller.h`](../../src/pump_controller.h)) mais reste une écriture de plus.
- Un changement de `timezoneId` en cours de journée peut produire un reset « avancé » ou « rétrograde ». Comportement acceptable : changer de fuseau est un événement rare.
- Si l'heure n'est pas encore synchronisée au boot (NTP pas reçu, RTC absente), le chargement des cumuls est différé (`_dailyLoaded = false`) → tant que `time_t` < `kMinValidEpoch` (14 nov. 2023), les cumuls ne sont pas restaurés depuis NVS et restent à zéro — **risque faible mais documenté**.

### Ce que ça verrouille
- Le namespace NVS `pool-daily` est réservé à ces compteurs : ne pas y écrire d'autres clés pour limiter la surface d'incompatibilité future.
- `kMinValidEpoch` est utilisé comme garde pour détecter « l'heure est-elle valide ? ». Constante consolidée dans [`constants.h`](../../src/constants.h:111).

## Références

- Code : [`src/pump_controller.h`](../../src/pump_controller.h) membres statiques `_dailyLoaded`, `_dailyCountersDirty`, `_lastDailySaveMs`
- Code : [`src/config.h`](../../src/config.h) struct `SafetyLimits` champ `currentDayDate[9]`
- Code : [`src/config.cpp`](../../src/config.cpp) `saveDailyCounters()`, `loadDailyCounters()`
- Doc régulation : [pump-controller.md](../subsystems/pump-controller.md) — gardes de sécurité et cumul journalier
- CHANGELOG [Unreleased] 2026-04-24 entrée « Persistance compteurs journaliers » + « Reset journalier »

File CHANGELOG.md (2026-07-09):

# Changelog - ESP32 Pool Controller

## [2.19.1] - 2026-07-09

### Ajouté

- **Pause mélange visible sur le tableau de bord** : le widget pH/ORP affiche désormais la **pause mélange hydraulique** post-injection (« Pause mélange : X min YY s »), au même titre que la stabilisation. Auparavant ce délai (20 min ORP / 15 min pH) n'apparaissait que dans le modal « État filtre », ce qui donnait l'impression d'un dosage bloqué sans explication. Nouveaux champs WebSocket `ph_mix_remaining_s` / `orp_mix_remaining_s`.

### Documentation

- `docs/subsystems/pump-controller.md` : nouvelle section « Cycle de régulation : chronologie stabilisation + pause mélange » (diagramme temporel + cadence de régulation ~1 injection / 20 min en ORP).
- Échos utilisateur dans `docs/features/page-orp.md`, `page-ph.md`, `page-dashboard.md`.

## [2.19.0] - 2026-07-08

### Ajouté

- **Mode d'installation (feature-056)** : nouveau réglage unique décrivant le câblage réel du PoolController, dans une section « Installation » dédiée (1er onglet des Paramètres) et une étape de l'assistant de 1ᵉʳ lancement. Trois choix :
  - **PoolController pilote la filtration** — alimentation permanente + sortie 12 V vers contacteur ; le contrôleur commande le relais, la programmation de filtration est active, le dosage est autorisé quand la filtration commandée est en marche.
  - **Alimenté par le circuit de filtration** — le contrôleur est alimenté en même temps que la pompe ; il ne pilote pas le relais et l'eau est présumée présente en permanence.
  - **Filtration externe signalée** *(nouveau cas)* — le contrôleur est alimenté en permanence et une domotique tierce lui signale l'état de la filtration via `POST /filtration/external-state` ou MQTT `.../filtration_external_state/set`. Sans signal « en marche » récent (au-delà de 3 min), l'eau est considérée absente et **le dosage est suspendu** (sécurité).
- Signalement de l'état de la filtration externe depuis Home Assistant (interrupteur) et sélection du mode d'installation (liste déroulante, libellés en français).
- **Aide intégrée au mode « Filtration externe signalée »** : bloc repliable dans les Paramètres avec des exemples prêts à l'emploi (commande HTTP `curl`, publication MQTT, automatisation Home Assistant), renseignés automatiquement avec l'adresse et le topic MQTT réels du contrôleur.

### Modifié

- La garde de sécurité « présence d'eau » du dosage repose désormais sur une résolution unique selon le mode d'installation (comportement inchangé pour les installations existantes, migration automatique).
- Le mode d'installation remplace et fusionne les anciens réglages « Fonctionnement Piloté/Continu » (section Régulation pH/ORP) et « filtration gérée par le PoolController ».

### Migration

- Mise à jour automatique de la configuration : « Piloté » → *PoolController pilote la filtration*, « Continu » → *Alimenté par le circuit de filtration*. Aucune action requise. Voir `docs/UPDATE_GUIDE.md` pour les cas de câblage particuliers.

## [2.18.3] - 2026-07-07

### Corrigé

- **Mode Boost — texte d'aide incohérent** : la description sous le widget Boost promettait toujours « filtration prolongée + cible ORP relevée », même quand l'effet réel affiché était « Surchloration seule » (filtration non gérée par le contrôleur) ou « Filtration prolongée seule » (ORP non automatique). Le texte est désormais cohérent : masqué quand le Boost est actif (la ligne « Effet » fait foi), et **prospectif honnête** quand inactif (« À l'activation : … ») en fonction de la configuration réelle. Purement UI, aucun impact sur le dosage.

---

## [2.18.2] - 2026-07-07

### Amélioré

- **Mode Boost — indication d'effet persistante (feature-055, finition feature-053/054)** : le widget Boost du tableau de bord affiche désormais **en permanence** les leviers réellement actifs — « Filtration prolongée + surchloration », « Surchloration seule », « Filtration prolongée seule », ou « Sans effet » (badge orange) —, complément persistant du toast fugace de la feature-054. L'info reste visible **après une activation depuis Home Assistant** et **après un rechargement de page**, via deux nouveaux champs WebSocket `boost_filtration_extended` (= filtration gérée par PoolController) et `boost_chlorine_boosted` (= régulation ORP en mode Automatique) calculés au vol. Affichage immédiat au clic Activer (mapping de la réponse `POST /boost/start`). **Purement informatif** : aucune logique de dosage ni de filtration modifiée.

### Documentation

- `docs/subsystems/ws-manager.md` : champs WS `boost_filtration_extended` / `boost_chlorine_boosted` (calculés au vol, buffer 1600 → 1664).
- `docs/features/page-dashboard.md` : ligne « Effet » persistante du widget Boost (4 libellés + badge `--warn`).

---

## [2.18.1] - 2026-07-07

### Amélioré

- **Mode Boost — signalement des leviers inertes (feature-054, finition feature-053)** : à l'activation, le Boost indique désormais quels leviers s'appliquent réellement selon la config. Si la filtration n'est pas gérée par PoolController (`filtration_enabled = false`), la filtration n'est pas prolongée ; si la régulation ORP n'est pas en mode Automatique, le chlore n'est pas relevé. Deux canaux d'information : (1) `startBoost()` logue un `warning` par levier inerte — couvre l'activation HTTP **et** MQTT/Home Assistant ; (2) la réponse 200 de `POST /boost/start` renvoie `filtration_extended` et `chlorine_boosted`, à partir desquels le dashboard affiche un **toast adaptatif** (nominal « vérifiez le taux de chlore », surchloration seule, filtration prolongée seule, ou « Boost sans effet »). **Purement informatif** : aucune logique de dosage, de garde ni de filtration n'est modifiée ; l'activation n'est jamais bloquée.

### Documentation

- `docs/API.md` : réponse 200 de `POST /boost/start` complétée avec `filtration_extended` / `chlorine_boosted` + note sur le log `warning`.
- `docs/features/page-dashboard.md` : tableau des 4 cas du toast adaptatif du Boost.
- `docs/subsystems/pump-controller.md` : section « Signalement des leviers inertes » (conditions d'effet de chaque levier, warnings `startBoost()`).

---

## [2.18.0] - 2026-07-06

### Fonctionnalités

- **Mode Boost — surchloration temporaire du jour (feature-053)** : après une forte fréquentation, un geste active le Mode Boost pour assainir davantage la piscine **pour la journée** : filtration prolongée (forçage dédié) + cible ORP relevée (`+60 mV`, plafonnée à 850 mV sous l'alerte). Surcouche **non destructive** (la config n'est jamais modifiée) auto-expirant au prochain minuit local. Pilotable depuis le dashboard (carte Boost avec expiration + toast « vérifier le taux de chlore avant baignade ») et depuis Home Assistant (switch « Boost »). L'activation est refusée si l'heure n'est pas synchronisée.

### Firmware

- **Régulation ORP — valeurs effectives boostées (feature-053)** : tant que le Boost est actif et **uniquement en mode de régulation ORP `automatic`**, la cible ORP effective = `min(orp_target + 60, 850)` mV et la limite journalière chlore effective = `min(max_chlorine_ml_per_day × 1,5, 1000)` mL — **bornes de sécurité dédiées figées par pool-chemistry**, jamais abaissées. En Manuel / Programmé, seule la filtration s'étend ; l'injection manuelle reste bornée à la limite normale. **Tous les autres garde-fous sont inchangés** (limite horaire, temps min d'injection, anti-rafale, injection si filtration active, watchdog) : le Boost n'ouvre aucun chemin de dosage. Décision structurante formalisée en [ADR-0025](docs/adr/0025-mode-boost.md).
- **Persistance** : état `boostState` (`active` + `untilEpoch`) persisté en NVS dédié (namespace `poolctrl`) → survit à un reboot dans la journée ; expiration honorée avant le reset des compteurs journaliers dans les deux branches de `tickDailyRollover()`.
- **MQTT / Home Assistant** : switch « Boost » (topic retain `{base}/boost` + commande `{base}/boost/set`, payload `ON`/`OFF`). L'état retombe automatiquement sur `OFF` à minuit. Activation refusée sans heure synchronisée (commande ignorée + resync HA).
- **Web / API** : routes `POST /boost/start` (auth WRITE, `409 time_not_synced` si horloge non synchronisée) et `POST /boost/stop` ; champs `boost_active` / `boost_until` (epoch) dans `/get-config` et le WebSocket.

### Documentation

- **[ADR-0025](docs/adr/0025-mode-boost.md)** créé (Accepté) : surcouche temporaire « valeurs effectives » + relèvement borné de la limite chlore, 4 bornes de sécurité et leur justification, alternatives écartées (mutation de config, relèvement non borné, durée fixe en heures, switch de mode), conséquences (edge boost court le soir, heure synchronisée requise, vérification chimique à la charge de l'utilisateur). Indexé dans `docs/adr/README.md`.
- `docs/MQTT.md` : topic `{base}/boost` + commande `{base}/boost/set`, entité discovery `switch` « Boost », section feature-053 dédiée.
- `docs/API.md` : routes `POST /boost/start` \| `/boost/stop`, champs `boost_active` / `boost_until` de `/get-config`.
- `docs/subsystems/ws-manager.md` : champs WS `boost_active` (bool) + `boost_until` (epoch).
- `docs/subsystems/pump-controller.md` : section Mode Boost (état, cible/limite effectives, expiration minuit, gate mode automatic), 4 constantes ajoutées au récapitulatif.
- `docs/features/page-dashboard.md` : carte Boost (activation, expiration, rappel baignade).

---

## [2.17.3] - 2026-07-06

### Firmware

- **Home Assistant — modes de régulation pH/ORP affichés en français (bug-ha-regulation-mode-labels)** : les selects « Mode Régulation pH » et « Mode Régulation ORP » exposaient dans HA les valeurs brutes anglaises `automatic`/`scheduled`/`manual` (feature-009), alors que l'UI web affiche « Automatique » / « Programmée » / « Manuelle ». Les deux selects affichent désormais ces libellés français via `value_template` / `command_template`, même technique que les modes filtration et éclairage. **Le protocole MQTT sur le fil reste strictement `automatic`/`scheduled`/`manual`** (topics d'état et handlers `PhRegulationMode`/`OrpRegulationMode` inchangés) : aucune automatisation Home Assistant existante n'est cassée.

### Documentation

- `docs/MQTT.md` : options des entités discovery pH/ORP passées aux libellés français, note dédiée aux templates, mise à jour de la note « Mode Filtration » (les selects de régulation ne sont plus en anglais).
- `docs/subsystems/mqtt-manager.md` : section « Selects Mode Régulation pH/ORP » (`value_template`/`command_template`, wire inchangé).

---

## [2.17.2] - 2026-07-06

### Firmware

- **Home Assistant — mode de programmation éclairage en liste déroulante (bug-ha-eclairage-select, finition feature-052)** : la programmation horaire de l'éclairage, jusque-là exposée en `switch` ON/OFF, est désormais un `select` **« Mode Éclairage »** avec les options **« Programmation »** / **« Désactivé »**, aligné sur le select « Mode Filtration ». Même technique que les libellés filtration : `value_template` / `command_template` traduisent l'affichage HA, le protocole sur le fil reste strictement `ON`/`OFF`. Le booléen `scheduleEnabled` et le handler `LightingSchedule` sont inchangés. Migration : un payload retain vide est publié sur l'ancien topic `homeassistant/switch/{id}_lighting_schedule/config` pour retirer le switch orphelin de HA.

### Documentation

- `docs/MQTT.md` : entité éclairage passée de `switch` à `select` « Mode Éclairage » (tableau discovery, section feature-052, note dédiée aux templates et au nettoyage de l'ancien switch).
- `docs/subsystems/mqtt-manager.md` : section « Select Mode Éclairage », migration de l'orphelin, mise à jour du handler et des compteurs.

---

## [2.17.1] - 2026-07-06

### Corrigé

- **Éclairage — rafraîchissement temps réel des champs de programmation (bug-ui-eclairage-refresh-ws, finition feature-052)** : l'écran Éclairage rafraîchit désormais ses champs de programmation (mode, heures début/fin) en temps réel lors d'un changement depuis Home Assistant, comme l'écran Filtration. Auparavant, `loadConfig()` (message WS `config`) repeuplait les champs filtration mais pas éclairage : il fallait quitter/revenir sur l'écran pour voir la valeur à jour. Correctif UI uniquement (`data/app.js`, miroir du mécanisme `filtrationDirty`) ; une saisie éclairage en cours n'est pas écrasée par un message WS. Aucun firmware modifié.

---

## [2.17.0] - 2026-07-06

### Fonctionnalités

- **Éclairage — section Programmation uniformisée avec la filtration (feature-052)** : la carte Programmation de la page Éclairage adopte les mêmes libellés que la filtration — select **« Mode d'éclairage »** avec options **« Programmation »** / **« Désactivé »**, heures **Début** / **Fin** en grille 2 colonnes. Les valeurs sous-jacentes (booléen `lighting_schedule_enabled`) et le backend sont inchangés ; seuls les libellés affichés changent. Le contrôle manuel (Allumer / Éteindre) reste indépendant.

### Firmware

- **Home Assistant — planning éclairage pilotable (feature-052)** : l'activation de la programmation et les heures de l'éclairage sont désormais exposées à Home Assistant, en miroir de la filtration (feature-051). Nouvelle entité `switch` « Programmation éclairage » (topic retain `{base}/lighting_schedule` + commande `.../set`, payload `ON`/`OFF` → booléen `scheduleEnabled`) et 2 entités `text` « Éclairage début » / « Éclairage fin » (`{base}/lighting_start` / `{base}/lighting_end` + `.../set`, format `HH:MM`). Validation `ON`/`OFF` et `HH:MM` (invalide → ignoré + `warning` + resync HA) ; changement persisté en NVS, appliqué via `lighting.update()`, et reflété dans l'UI web sous ≤ 5 s (broadcast WS `config`). `publishLightingState()` enrichie et publiée au cycle périodique. Le booléen `scheduleEnabled` est conservé côté firmware (pas de stringification, cf. feature-028). Aucun chemin de dosage touché.

### Documentation

- `docs/MQTT.md` : 3 topics d'état + 3 commandes `/set` éclairage, 3 entités discovery (1 `switch` + 2 `text` `HH:MM`), section feature-052 dédiée, compte discovery total mis à jour.
- `docs/subsystems/mqtt-manager.md` : `InboundCmdType` `LightingSchedule`/`LightingStart`/`LightingEnd`, handler planning éclairage, `publishLightingState()` enrichie, compteurs de publish (états 23 / discovery 20) et compte discovery (44).
- `docs/features/page-lighting.md` : nouveau libellé « Mode d'éclairage », options Programmation/Désactivé, exposition HA du planning, indépendance du contrôle manuel.

---

## [2.16.0] - 2026-07-06

### Firmware

- **Home Assistant — heures de filtration modifiables (feature-051)** : les heures de début et de fin du créneau de filtration sont désormais exposées à Home Assistant en 2 entités `text` **éditables** (« Filtration début » / « Filtration fin »), complétant le select « Mode Filtration ». Nouveaux topics retain `{base}/filtration_start` / `{base}/filtration_end` (état, format `HH:MM`) et commandes `{base}/filtration_start/set` / `{base}/filtration_end/set`. La saisie est validée `HH:MM` (format invalide → ignoré + `warning` + resync HA sur la valeur réelle) ; le changement efface les overrides marche/arrêt forcés, applique le planning immédiatement, persiste en NVS et se reflète dans l'UI web sous ≤ 5 s (broadcast WS). **Effet réel en mode Programmation** : en mode **Auto**, les heures sont recalculées par la température (une saisie HA est alors consultative et auto-corrigée). Aucun chemin de dosage touché.

### Documentation

- `docs/MQTT.md` : 2 topics d'état + 2 commandes filtration_start/end, 2 entités discovery `text` (pattern `HH:MM`), section feature-051 dédiée, sémantique Programmation/Auto, compte discovery mis à jour (41).
- `docs/subsystems/mqtt-manager.md` : `InboundCmdType` `FiltrationStart`/`FiltrationEnd`, handler groupé (validation `HH:MM` avant mutex, efface overrides, `filtration.update()` hors mutex sur `loopTask`), `publishFiltrationState()` enrichi (4 topics).

---

## [2.15.0] - 2026-07-06

### Firmware

- **Home Assistant — libellés du mode filtration en français et non ambigus (bug-ha-filtration-mode-labels)** : le select « Mode Filtration » exposait dans HA les valeurs brutes `auto`/`manual`/`force`/`off`, alors que l'UI web affiche « Auto / Programmation / Manuel / Désactivé ». Au-delà de l'écart de langue, c'était trompeur : `manual` correspond à « Programmation » (créneau à heures fixées) et `force` à « Manuel » (contrôle ON/OFF sans planning) — l'inverse de l'intuition. Le select HA affiche désormais les **libellés français** via `value_template` (état brut → libellé) et `command_template` (libellé → valeur brute). **Le protocole MQTT sur le fil reste strictement `auto`/`manual`/`force`/`off`** (topic d'état et handler de commande inchangés) : aucune automatisation Home Assistant existante n'est cassée. Les selects de régulation pH/ORP restent en valeurs anglaises (non trompeuses).

### Documentation

- `docs/MQTT.md` : sémantique des 4 modes filtration détaillée sur les topics d'état/commande, note dédiée sur les templates d'affichage du select (libellés français côté HA, wire inchangé).
- `docs/subsystems/mqtt-manager.md` : nouvelle section sur les `value_template`/`command_template` du select `filtration_mode` (traduction affichage uniquement, `doc.clear()` anti-fuite, handler brut inchangé).

---

## [2.14.1] - 2026-07-06

### Firmware

- **MQTT / UI temps réel — synchronisation WebSocket (bug-sync-ws-config-mqtt)** : quand la configuration est changée depuis Home Assistant (consignes pH/ORP, modes de régulation, volumes quotidiens, mode filtration, éclairage), l'UI web se met désormais à jour automatiquement sous ≤ 5 s **sans recharger la page**. Auparavant, seul le chemin HTTP `POST /save-config` déclenchait le broadcast WebSocket `config` ; les commandes reçues par MQTT modifiaient bien la config (persistée + republiée sur le broker) mais ne notifiaient jamais les clients WS connectés. Correctif : `MqttManager::drainCommandQueue()` appelle `wsManager.requestConfigBroadcast()` une fois en fin de drain dès qu'au moins une commande (hors `Reboot`) a été traitée — le message `config` part au prochain cycle WS. Broadcast unique et idempotent (coalescé), aucun contrat modifié.

### Documentation

- `docs/subsystems/mqtt-manager.md` : `drainCommandQueue()` déclenche un broadcast WS `config` après une commande modifiant la config (cohérence UI temps réel, même effet que `POST /save-config`).
- `docs/subsystems/ws-manager.md` : le chemin MQTT (`drainCommandQueue`) documenté comme second déclencheur du message `config`.

---

## [2.14.0] - 2026-07-06

### Firmware

- **MQTT / Home Assistant — complétude de couverture (feature-050)** : issu d'un audit web/API vs MQTT/HA (périmètre « rentable »). Ajout de 5 entités auto-discovery HA. **Cumuls journaliers de dosage exposés** : nouveaux topics retain `{base}/ph_daily_ml` et `{base}/orp_daily_ml` (cumul injecté en mL, dédup au cycle 10 s, retombe à 0 à minuit) + 2 `sensor` HA « Dosage pH/Chlore aujourd'hui » (`state_class: measurement`). **Volumes quotidiens programmés commandables** : les topics `{base}/ph_daily_target_ml` / `{base}/orp_daily_target_ml` deviennent commandables via `.../set` + 2 `number` HA « Volume quotidien pH/Chlore » (min 0 / max 2000 / step 10 mL) — payload non numérique ignoré + `warning`, clamp négatif → 0, **REFUS si valeur > limite journalière VIVE** (`maxPhMlPerDay` / `maxChlorineMlPerDay`) + resync HA (condition pool-chemistry), persistance NVS. **Bouton Redémarrer** : topic `{base}/reboot/set` + `button` HA `device_class: restart` — redémarrage différé propre (flush MQTT `offline` puis restart, même séquence que `POST /reboot`).

### Documentation

- `docs/MQTT.md` : nouveaux topics d'état et de commande, 5 entités discovery (compte total 39), section feature-050 détaillée, et **nouvelle section « Exclusions volontaires »** documentant comme une politique assumée ce qui n'est délibérément pas exposé en MQTT/HA (injections manuelles, limites de sécurité, calibration/OTA/factory-reset/Wi-Fi/auth, transients d'affichage, historique).
- `docs/subsystems/mqtt-manager.md` : `InboundCmdType` `PhDailyTarget`/`OrpDailyTarget`/`Reboot`, handlers volume quotidien (garde limite vive) et reboot différé (flag consommé en tête de drain), compte discovery mis à jour.

---

## [2.13.0] - 2026-07-06

### Firmware

- **Infrastructure — repartitionnement flash, layout v4 (feature-049)** : les slots firmware `app0`/`app1` passent de 1664 à **1792 KB** (+128 KB chacun), pris sur la partition `spiffs` réduite de 576 à **320 KB** (offset déplacé à `0x390000`) — rendu possible par la pré-compression gzip (feature-048, payload FS 155 KB, soit 48 % de la nouvelle partition). Occupation firmware ≈**78,5 %** (marge par slot 264 → ~392 KB). Partitions `nvs`, `history` et `coredump` strictement inchangées : **config, historique et coredump préservés**. ⚠️ **Mise à jour par câble USB requise une seule fois** (`./deploy.sh all`) — l'OTA ne peut pas réécrire la table de partitions ; **ne jamais pousser le FS v4 en OTA sur un appareil en table v3** ; ne pas utiliser `./deploy.sh factory` (efface la NVS). L'OTA redevient normal ensuite. Quatuor aligné : `partitions.csv`, `platformio.ini` (`filesystem_size = 327680`), `build_fs.sh` (`-s 327680`), `deploy.sh` (`LITTLEFS_OFFSET=0x390000`, contrôle de taille 327680 avec reconstruction automatique d'une image de mauvaise taille).

### Documentation

- Nouvel [ADR-0024](docs/adr/0024-partitions-layout-v4.md) : partitions app à 1792 KB (layout v4) — contexte (gzip feature-048 → `spiffs` occupée à 27 %), alternatives écartées (statu quo — marge suffisante aujourd'hui mais flash USB groupable avec la release ; +64 KB — demi-mesure ; reprendre `history` — données à préserver), conséquences (flash USB unique, interdiction FS v4 en OTA sur table v3, granularité 64 KB des slots). [ADR-0019](docs/adr/0019-partition-app-1664k.md) marqué « Superseded by ADR-0024 ».
- `docs/UPDATE_GUIDE.md` : nouvelle note « Migration layout v3 → v4 (v2.13.0) » — procédure USB, interdiction explicite de l'OTA v4-sur-v3 (métadonnées LittleFS discordantes), vérifications post-flash (Infos système : FS ~320 KB, historique présent).
- `docs/BUILD.md` : taille filesystem 327 680 o = 320 KB (layout v4, ADR-0024), occupation firmware actualisée (~78,5 %, marge ~392 KB).

---

## [2.12.1] - 2026-07-06

### Frontend

- **Performance — assets web pré-compressés gzip (feature-048)** : `minify.js` gzippe (zlib niveau 9) tous les fichiers texte (`.js`, `.html`, `.css`) après minification — seule la variante `.gz` est embarquée dans le filesystem, images/icônes inchangées. ESPAsyncWebServer sert nativement ces fichiers avec `Content-Encoding: gzip` sur tous les chemins (routes HTML explicites, `serveStatic`, portail captif) — **aucune modification firmware**. Payload FS **443 → 155 KB** (partition `spiffs` 78 % → 27 %), **chargement des pages ~4× plus rapide** (le débit de l'ESP32 est le facteur limitant sur mobile). Routes API/JSON non concernées ; un `curl` brut sur un asset statique reçoit du gzip (utiliser `--compressed`).

### Documentation

- `docs/BUILD.md` : étape gzip du pipeline FS (`minify.js` → `data-build/` `.gz` → `build_fs.sh`), règle « jamais de fichier texte non compressé dans `data-build/` », caveat `curl --compressed`.
- `docs/subsystems/web-server.md` : mécanisme de résolution `.gz` d'ESPAsyncWebServer sur les deux chemins de serving (références lib vérifiées).

---

## [2.12.0] - 2026-07-06

### Frontend

- **UX — remplacement des 43 dialogues natifs (feature-031)** : plus aucun `alert()` / `confirm()` dans l'UI. Les **31 `alert()`** informatifs passent par les toasts `showToast` existants (mapping `error`/`success`/`info` selon le contexte) ; les **12 `confirm()`** (actions destructives : purge historique, effacement logs/coredump, déconnexion Wi-Fi, redémarrage, reset sondes, reset usine…) passent par une nouvelle **modale de confirmation maison** `confirmDialog({title, message, confirmLabel, cancelLabel, danger}) → Promise<boolean>` — `<dialog id="confirm-modal">` statique (pattern `probe-modal`), focus initial sur **Annuler**, fermeture `Escape`/backdrop = annulation, réentrance refusée, contenu injecté en `textContent` (anti-XSS), fallback `window.confirm` si `<dialog>` indisponible, **variante danger (bouton rouge)** pour les 7 actions irréversibles. Refus = défaut sûr sur les 12 flux async convertis (revue site par site). Le **reset usine conserve sa double confirmation** (« Réinitialiser » puis « Tout effacer »). Emojis ⚠ retirés des messages — le rouge porte la sévérité.
- **Page « À propos » mise à jour** : retrait des crédits obsolètes DFRobot_PH et Adafruit ADS1X15 (matériel remplacé par les modules Atlas Scientific EZO en I²C natif depuis la feature-021) et de Playwright (jamais utilisé) ; ajout des modules EZO et des tests natifs Unity (185 tests, CI).

### Documentation

- `docs/features/README.md` : nouvelle section « Composants transverses » — API du helper `confirmDialog`, règle « toute action destructive passe par `confirmDialog` ».
- `docs/features/page-settings.md` : confirmations via modale maison (logs, coredump, reset usine à double confirmation).

---

## [2.11.2] - 2026-07-06

### Firmware

- **Sécurité — comparaison de token à temps constant (feature-028)** : le token API n'est plus comparé via `==`/`!=` sur `String` (court-circuit au premier octet différent → canal temporel sur le contrôle d'accès central). Nouvelle comparaison `constantTimeEquals` (`auth.cpp`) : longueur vérifiée d'abord (non secrète — format fixe 32 hexa), puis accumulation XOR/OR de **tous** les octets sans court-circuit. Appliquée à l'auth **HTTP** (`checkTokenAuth`) ET à l'auth **WebSocket** via la nouvelle API publique `AuthManager::secureTokenEquals()` — la revue de code a relevé que le WS comparait encore le token en `!=` (corrigé avant merge). Plus aucune comparaison directe du token dans le code. Code mort de debug (`maskedReceived`/`maskedExpected`) supprimé. Protections préservées : refus du token en query param, token jamais loggué en clair.
- **Sécurité — retrait complet du mécanisme CORS ([ADR-0023](docs/adr/0023-politique-cors-retrait.md))** : le CORS était partiellement implémenté et trompeur (seul le **premier** origin de la liste était posé, statiquement, sans validation par requête — le multi-origines configuré était silencieusement ignoré). Décision : **politique même-origine stricte** (l'UI est servie par l'ESP32, offline first). Retirés : bloc `DefaultHeaders` CORS + `setCorsHeaders` (code mort), champ `AuthConfig::corsAllowedOrigins` + persistance NVS (valeur existante orpheline, pas de migration), champ `auth_cors_origins` de `/get-config`/`/save-config` et du message WebSocket `config`, preflight `HTTP_OPTIONS`. En-têtes CSP / `X-Content-Type-Options` / `X-Frame-Options` conservés. Toute intégration cross-origin future : reverse proxy ou nouvel ADR.

### Frontend

- **Page Paramètres → Sécurité** : card CORS supprimée (champ `#auth_cors_origins` + bouton `#cors-save-btn`) — mécanisme retiré côté firmware.

### Documentation

- Nouvel [ADR-0023](docs/adr/0023-politique-cors-retrait.md) : retrait complet du CORS, politique même-origine stricte (alternatives écartées : réparation multi-origines par requête — ESPAsyncWebServer s'y prête mal, besoin inexistant ; origin unique assumé — mécanisme conservé sans besoin réel).
- `docs/subsystems/auth.md` : section « Comparaison de token à temps constant » + règle « jamais `==`/`!=` sur le token » ; `docs/subsystems/ws-manager.md`, `docs/subsystems/web-server.md`, `docs/features/page-settings.md`, `docs/API.md` : politique même-origine documentée, mentions CORS retirées.

---

## [2.11.1] - 2026-07-06

### Firmware

- **Fiabilité — plus aucune attente infinie de mutex (feature-027)** : les **24 prises de mutex** encore en `portMAX_DELAY` (mqtt_manager ×9, logger ×7, history ×6, config ×2) sont désormais **bornées** — la `loopTask` ne peut plus être figée jusqu'au reset watchdog (30 s) par une contention (ex. mutex tenu pendant une I/O LittleFS lente). Dégradation gracieuse par site, comportement nominal strictement inchangé :
  - **Logger** (`kLoggerMutexTimeoutMs = 100 ms`) : politique **silencieuse anti-récursion** (jamais de `systemLogger` dans les chemins d'échec) — entrée perdue comptée dans le compteur diagnostic interne `_droppedLogs`, lectures → résultat vide, `clearAll()`/`flushToDisk()` abandonnent **avant** toute modification (pas d'état incohérent).
  - **Historique** (`kHistoryMutexTimeoutMs = 2000 ms`, dimensionné sur consolidation + `saveToFile` ~1–1,5 s) : point/consolidation sautés avec **retry naturel** (`lastRecord`/`lastSave` non avancés), lectures → vecteur vide, `clearHistory()` devient `bool` — la route `POST /history/clear` répond **`503` « Historique occupé — réessayer »** en cas d'échec.
  - **Config** (`kConfigMutexTimeoutMs`, récursif) : `saveMqttConfig` → `error` (config RAM appliquée, persistance NVS perdue) ; `saveProductConfig` → dirty flag conservé → retry au prochain passage.
  - **MQTT** : snapshots de publication sautés (republication naturelle au prochain cycle, topics retain) ; commande HA reçue → **abandon complet** (aucun état partiel) + **resync immédiat** de l'entité HA sur l'état réel (`publishFiltrationState()`/`publishTargetState()`).
  - Warns de timeout **throttlés à 1/min/site** (`kMutexTimeoutWarnThrottleMs = 60000`). Audit `grep portMAX_DELAY src/` à blanc. Revue de concurrence complète (Approved), 185/185 tests natifs verts.

### Documentation

- `docs/subsystems/logger.md`, `docs/subsystems/history.md`, `docs/subsystems/mqtt-manager.md` : stratégie de timeout mutex et politique d'échec par site (dont `_droppedLogs` write-only volontaire et pattern accepté de lecture sans mutex dans le resync filtration).

---

## [2.11.0] - 2026-07-06

### Firmware

- **Sécurité — vérification d'intégrité SHA-256 avant flash OTA (feature-026, [ADR-0022](docs/adr/0022-verification-integrite-ota.md))** : la règle de sécurité #6 (« toujours vérifier la signature/CRC avant flash ») est désormais satisfaite. L'empreinte SHA-256 de chaque flux OTA est calculée **au fil de l'eau** (`OtaStreamHasher`, mbedtls accéléré matériellement, non bloquant pour AsyncWebServer) et comparée à l'empreinte de référence — le champ `digest` (`sha256:<64hex>`) publié par l'API GitHub Releases pour chaque asset (présence vérifiée sur la release réelle v2.5.2, zéro changement du process de release). **Chemin GitHub fail-closed strict** : `/check-update` relaie les champs additifs `firmware_digest`/`filesystem_digest`, l'UI les repasse en paramètre `digest=` **requis** de `/download-update` (même modèle de menace que l'URL déjà relayée : whitelist d'hôtes + auth CRITICAL). Digest absent → `400 integrity_digest_missing` (refus avant toute connexion) ; malformé → `400 integrity_digest_invalid` ; mismatch (image corrompue/tronquée, coupure WiFi incluse) → **firmware** : `Update.abort()` avant tout `end()` — l'image n'est **jamais activée**, version courante conservée ; **filesystem** : `422` sans restart, remontage LittleFS best-effort, réinstallation FS requise (firmware intact et bootable). **Upload manuel `/update`** : empreinte toujours calculée et **loggée** ; champ POST `sha256` optionnel (mismatch ou valeur malformée → flash refusé) — fail-open documenté, l'utilisateur est physiquement présent. ArduinoOTA/espota inchangé (déjà protégé par le MD5 du protocole). Tout refus émet un log `CRITICAL` avec empreintes attendue/calculée. Logique pure `ota_integrity_logic` (parse, comparaison **temps constant**, formatage — pattern ADR-0017), **22 tests natifs ajoutés** (185/185 verts).
- **Corrigé — verrou anti-upload concurrent sur `/update`** : deux uploads simultanés corrompaient l'état statique du handler (hasher, empreinte attendue, progression). Une seule session propriétaire à la fois (`g_uploadOwner`) : le 2ᵉ client reçoit **`409`** ; déconnexion du client en cours de transfert → `Update.abort()` + réarmement du dosage (`setOtaInProgress(false)`) + libération du verrou ; owner périmé repris si `!Update.isRunning()`.
- **Corrigé — progression entre deux uploads (AC5)** : le throttle de log de progression (`static lastLog`) n'était pas réinitialisé entre deux uploads sans reboot — désormais remis à zéro à chaque début d'upload.
- **Corrigé — pompes inhibées après échec `Update.begin()`** : `setOtaInProgress(true)` n'était pas réarmé sur ce chemin d'échec — les pompes doseuses restaient coupées jusqu'au reboot. Appariement `setOtaInProgress` garanti sur tous les chemins terminaux (relevé en revue).

### Frontend

- **Page Mise à jour — fail-closed visible (feature-026)** : bouton **Installer désactivé** avec message explicite si la release GitHub ne fournit pas d'empreinte d'intégrité ; messages d'erreur français distincts sur refus (`Empreinte d'intégrité absente ou invalide…`, `Échec de la vérification d'intégrité — image refusée, version actuelle conservée.` + invite à réinstaller le filesystem le cas échéant) ; le digest est transmis automatiquement à `/download-update`.

### Documentation

- Nouvel [ADR-0022](docs/adr/0022-verification-integrite-ota.md) : SHA-256 comparé au digest de l'API GitHub, fail-closed chemin GitHub, empreinte loggée + param optionnel en upload manuel, transit du digest par l'UI (alternatives écartées : `Update.setMD5` — ne couvre pas le flux FS écrit via `esp_partition_write` ; re-fetch API côté firmware — double le pic RAM TLS ; signature asymétrique — feature ultérieure ; relecture flash post-write — redondante). Conséquences assumées : anciennes releases sans digest refusées par l'UI ; usure flash sur digest faux (image écrite avant refus).
- `docs/subsystems/ota-manager.md` : politique d'intégrité par chemin, verrou anti-upload concurrent, appariement `setOtaInProgress`, constantes `kOtaSha256HexLen`/`kOtaSha256Prefix`, logs CRITICAL.
- `docs/API.md` : champs `firmware_digest`/`filesystem_digest` de `/check-update`, param `digest=` requis de `/download-update` (erreurs 400/422), param `sha256` optionnel et `409` de `/update`.
- `docs/UPDATE_GUIDE.md` : section « Vérification d'intégrité SHA-256 » (cas mismatch firmware/FS, release sans digest, upload manuel) + dépannage.

---

## [2.10.1] - 2026-07-06

### Firmware

- **Corrigé — alerte « limite journalière atteinte » répétée toutes les 60 s** : après le latch de la limite journalière pH ou ORP, le health check de `main.cpp` (60 s) republiait l'alerte MQTT `ph_limit`/`orp_limit` (topic `{base}/alerts`, non-retained) et son log `WARN` **à chaque cycle**, indéfiniment. L'alerte n'est désormais émise qu'à la **transition** vers la limite atteinte (edge-trigger, même flag que l'alarme écran UART) — une seule ligne WARN par épisode. L'état permanent pour Home Assistant reste porté par le binary_sensor `{base}/ph_limit` / `{base}/orp_limit` (retain, inchangé). Après un reboot avec limite déjà latchée : une alerte unique au premier health check (~60 s), voulu. Alarme écran UART : comportement identique.
- **Corrigé — libellé pH codé en dur** : le message d'alerte disait « Limite journalière pH- atteinte » même en configuration pH+. Libellé désormais dynamique (« pH+ » / « pH- » selon `phCorrectionType`, même règle que le log CRIT de `pump_controller`). Libellé ORP (« chlore ») inchangé, toujours exact.

### Documentation

- `docs/MQTT.md` : sémantique de transition des alertes `ph_limit`/`orp_limit` précisée (événement non-retained vs binary_sensor retain, libellé dynamique).

---

## [2.10.0] - 2026-07-05

### Firmware

- **Sécurité — détection capteur pH/ORP figé (feature-022 re-scopée, P2.1/P2.2)** : un module EZO qui répond sans erreur I²C mais retourne indéfiniment la **même valeur** (variance nulle — électronique figée, sonde HS côté BNC) est désormais détecté : nouvelle classe pure `FrozenDetector` (« run ancré » O(1) : bornes `runMin`/`runMax` + longueur de run, ré-ancrage dès qu'une lecture sort de la bande) composée dans `SensorFilter` et alimentée **uniquement par les lectures brutes acceptées** (l'état figé persiste pendant une rafale de rejets). Figé = **30 lectures valides** dans une bande < epsilon (`kSensorFrozenSamples` = 30 ≈ 2,5 min ; `kSensorFrozenEpsilonPh` = 0.0005 = ½ LSB EZO pH ; `kSensorFrozenEpsilonOrp` = 0.05 mV = ½ LSB EZO ORP — un capteur vivant bruite ≥ ±1 LSB, un toggle de 1 LSB casse le run, validé pool-chemistry). Figé ⇒ `ready()` = false ⇒ **dosage bloqué fail-closed** par la garde `FilterNotReady` existante (aucune modification des gardes verrouillées) ; **sortie immédiate sans re-warmup** dès une lecture vivante. Log `critical` edge-triggered `[SENSOR_FROZEN]` (+ `info` à la levée) et alerte MQTT retain `{base}/alerts/sensor_frozen` (JSON, clear payload vide). Consigne terrain : en cas de faux positifs, **durcir N, jamais élargir epsilon**.
- **Température figée warning-only (P2.3)** : `FrozenDetector` dédié à la sonde DS18B20 « eau » (N = 900 ≈ 30 min à 2 s, epsilon 0.03 °C < ½ LSB 12 bits, alimenté par les valeurs brutes non arrondies) — log `warning` seulement, **aucun impact dosage/filtration** (effets réels : compensation EZO pH + planning auto filtration), hors alerte MQTT `sensor_frozen`.
- **MQTT/HA — états problème capteur (P1.1)** : 2 nouveaux topics state retain `{base}/ph_sensor_problem` / `{base}/orp_sensor_problem` (`ON` = capteur **stale OU figé**, `OFF` sinon, publication dédupliquée) + 2 entités auto-discovery `binary_sensor` `device_class: problem` (« Capteur pH — problème » / « Capteur ORP — problème », `unique_id: poolcontroller_ph|orp_sensor_problem`) — l'indisponibilité capteur devient visible dans HA sans parser les JSON d'alerte.
- 11 tests natifs ajoutés (FrozenDetector + intégration SensorFilter), 163/163 verts. Validé pool-chemistry (GO, 4 conditions levées).

### Frontend

- **Dashboard — segment « Capteur indisponible » (P1.2)** : nouveau segment **danger, priorité 0 (la plus haute)** dans le badge multi-états des cartes pH/ORP, piloté par les valeurs `ph`/`orp` `null` du WS (capteur stale ou figé) — aucun champ WS nouveau. Garde anti-faux-positif au boot (aucun segment tant qu'aucun message WS reçu). Échelle des priorités désormais : 0 = capteur indisponible, 1 = hors plage, 2 = limite journalière, 3 = cumul ≥ 75 %, 4 = stock faible (toujours max 2 segments affichés).

### Documentation

- `docs/MQTT.md` : nouvelle section feature-022 (2 topics `*_sensor_problem` + 2 entités discovery + alerte `alerts/sensor_frozen` ajoutée au tableau des alertes dédiées).
- `docs/subsystems/sensors.md` : nouvelle section « Détection capteur figé » (FrozenDetector, run ancré, ½ LSB, intégration `ready()`, sortie immédiate, température warning-only, consigne durcir-N) ; API, états du filtre et constantes complétés.
- `docs/subsystems/mqtt-manager.md` : blocs de publication problème capteur / sensor_frozen, caches de dédup, discovery 32 → 34 entités.
- `docs/features/page-dashboard.md` : segment « Capteur indisponible » + échelle de priorités 0-4.

Écartés explicitement (documentés dans la spec) : compteurs de refus par cause, refresh périodique du cache cal_points, topics `dose_refusal`, ring RAM injections.

---

## [2.9.2] - 2026-07-05

### Firmware

- **Corrigé — écrêtage au reliquat pour l'injection manuelle** : demander une injection manuelle supérieure au reliquat du quota journalier (ex. limite 50 mL, cumul réel 39,4 affiché « 39 », demande de 11 mL) était refusée avec un message contradictoire « reste disponible aujourd'hui : 11 mL » (`lroundf` arrondissait le reliquat au plus proche alors que la garde raisonnait en volume exact). Désormais, `/ph|orp/inject/start` **écrête automatiquement la demande au reliquat** (durée recalculée arrondie **vers le bas** : le volume effectif ne re-déborde jamais la limite) au lieu de refuser — nouveau log info « [Injection] pH|ORP : volume écrêté de X à Y mL (reliquat journalier) ». En fin naturelle, le crédit plancher (v2.9.1) porte le cumul **exactement à la limite** → latch `ph/orp_limit_reached` + badge « Limite journalière atteinte ». Le refus `daily_limit` ne subsiste que si le reliquat est **nul ou < 1 s de pompe**, et son message/champ `remaining_ml` arrondissent désormais **vers le bas** (`floorf` — plus jamais de promesse intenable). Cas double-clamp (reliquat > 10 min de pompe) : le plafond `kManualInjectMaxDurationS` gagne, crédit = volume effectif. Garde pure `evaluateManualInject()` inchangée ; symétrie pH/ORP + chemin legacy `?duration=` ; logs de démarrage d'injection à 1 décimale (reco cosmétique code-reviewer). Validé pool-chemistry (GO), 152/152 tests natifs verts.

### Documentation

- `docs/API.md` : écrêtage automatique au reliquat documenté sur `/ph|orp/inject/start` ; sémantique **floor** du `remaining_ml` du 409 `daily_limit`.
- `docs/subsystems/pump-controller.md` : section « Crédit plancher » complétée (écrêtage → `creditMl = reliquat` entier ; double-clamp → `effectiveMl`).
- `docs/features/page-ph.md`, `page-orp.md` : mention de l'écrêtage automatique dans la garde journalière prédictive.

---

## [2.9.1] - 2026-07-05

### Firmware

- **Corrigé — sous-compte du cumul journalier en fin d'injection manuelle volumée** : demander exactement le reliquat du quota journalier (ex. limite 50 mL, injection 50 mL — frontière `==` acceptée depuis feature-006) laissait le cumul de sécurité à 49,x mL : l'intégration débit × temps perdait la dernière tranche (pompe coupée avant le tick de comptage suivant) et l'arrondi à la seconde → `ph/orp_limit_reached` jamais latché, badge dashboard « Cumul 98 % » figé au lieu de « Limite journalière atteinte ». À la **fin naturelle** d'une injection manuelle volumée, le compteur journalier de sécurité est désormais **planché au volume promis** (`creditManualInjectionFloor` : `daily = max(daily, startCumul + effectiveMl)` ; rollover minuit pendant l'injection → volume entier crédité au jour nouveau, conservateur). **Jamais de crédit sur arrêt anticipé** (stop manuel `/inject/stop`, interruption filtration) : l'intégration réelle fait foi. Propriété validée pool-chemistry (GO) : le registre de sécurité **ne sous-compte jamais** (sur-compte possible de quelques dixièmes de mL) ; le suivi produit (stock) reste sur l'intégration réelle (légère sous-estimation cumulative possible, assumée). Nouveau log info « [Sécurité] Compteur journalier pH|ORP ajusté de X à Y mL (crédit fin d'injection manuelle) ». Symétrie pH/ORP. 152/152 tests natifs verts.

### Documentation

- `docs/subsystems/pump-controller.md` : nouvelle section « Crédit plancher à la fin naturelle » (propriété fail-safe, tableau des 3 chemins d'arrêt, rollover minuit, suivi produit non planché et dérive de stock, nouveaux logs) ; `creditManualInjectionFloor` ajoutée à l'API publique.

---

## [2.9.0] - 2026-07-05

### Frontend

- **Dashboard — badge multi-états des cartes pH/ORP (feature-012, périmètre réduit sur avis ux-ui-designer)** : nouveau segment **« Cumul XX % »** (warning) affiché à partir de **75 %** du quota journalier (même arithmétique que la barre des pages /ph et /orp : arrondi des entrées, plafond 100 %), masqué quand la limite est atteinte (le segment « Limite journalière atteinte » prend le relais), quand la limite n'est pas configurée ou données indisponibles. Règle de composition **formalisée** (`composeSensorBadge`) : priorité hors plage (danger) > limite atteinte > cumul ≥ 75 % > stock faible, **maximum 2 segments** (troncature aux 2 plus prioritaires), variant `danger` si un segment danger retenu sinon `warning`. Changement visible : « hors plage + limite atteinte » simultanés affichent désormais **les 2 segments** (avant : seul « hors plage »). 100 % UI (`data/app.js`), aucun changement firmware.
- **Dashboard — stabilisation par pompe (feature-012)** : le statut « Stabilisation : X min YY s » des cartes pH/ORP consomme les champs **par pompe** `ph/orp_stab_remaining_s` (feature-006, repli sur le champ global pour les firmwares plus anciens) — chaque carte affiche la stabilisation de **sa** pompe (une calibration ORP n'affiche plus « Stabilisation » sur la carte pH, et inversement).

### Documentation

- `docs/features/page-dashboard.md` : nouvelles sections « Badge multi-états des cartes pH/ORP » (4 segments, priorité, max 2, seuil 75 %) et « Statut dosage et stabilisation par pompe » ; champs WS consommés complétés.

---

## [2.8.0] - 2026-07-05

### Firmware

- **Régulation — répartition 24 h du mode Programmée (feature-011)** : le volume quotidien du mode `scheduled` (pH et ORP) n'est plus injecté d'un bloc en début de filtration (pic de concentration localisé) mais **réparti par fenêtres de 15 min** alignées sur l'horloge (`kScheduledWindowMinutes`) sur la plage de filtration restante, **bornée à minuit** ([ADR-0021](docs/adr/0021-repartition-scheduled.md)). Le volume de fenêtre (`restant / fenêtres restantes`, recalculé à chaque fenêtre — auto-corrigé après changement de cible, injection manuelle comptée dans le cumul, retard subi ou reboot) est borné par le **budget horaire partagé** ([ADR-0020](docs/adr/0020-budget-horaire-dosage-unique.md), warning edge-triggered si tronqué) et **reporté** si l'injection durerait moins de 30 s (`minInjectionTimeMs`, anti short-cycling — avec une pompe rapide et une petite cible, les premières fenêtres sont reportées et les injections démarrent quand l'horizon se resserre : comportement voulu). **Pas de rattrapage J+1** : le reliquat non injecté à minuit est perdu (log `info` dans `tickDailyRollover`). Décision extraite en fonction pure testable `evaluateScheduledDose()` (`dosing_logic`, pattern ADR-0017) + helper pur `remainingRangeMinutes()` (`schedule_logic`) ; fail-closed strict (watchdog inactif, heure locale invalide, horizon ou débit nuls → aucune injection, warning unique). Le **ring anti-rafale partagé est consulté avant tout démarrage** (6/min, 20/15 min, mêmes seuils que `canDose`) ; l'exemption `cyclesToday` de la branche scheduled est **conservée et documentée** (démarrages bornés structurellement ≤ 4/h par le cadencement — arbitrage R4 validé pool-chemistry). Mode filtration `continu` : horizon = fin de journée (le dosage hors plage reste permis). Validé pool-chemistry (GO, 5 conditions levées) ; **17 tests natifs ajoutés** (12 `evaluateScheduledDose` + 5 `remainingRangeMinutes`), 152/152 verts.
- **WebSocket** : nouveaux champs `ph_scheduled_flow_ml_per_min` / `orp_scheduled_flow_ml_per_min` (float 1 décimale = débit moyen planifié restant ; `null` hors mode scheduled / hors plage / heure invalide). Buffer `sensor_data` 1472 → 1536 octets.

### Frontend

- **Cartes Régulation pH/ORP — bloc Programmée (feature-011)** : nouvelle ligne « Débit calculé : X,X mL/min » (« — » avec infobulle « Hors plage de filtration ou données indisponibles » quand la valeur est `null`) + hint statique « Le volume non injecté avant minuit est perdu (pas de report au lendemain). ». Pas d'affichage « sur Y h restantes » (l'horloge du navigateur peut différer de celle de l'ESP32).

### Documentation

- Nouvel [ADR-0021](docs/adr/0021-repartition-scheduled.md) : répartition scheduled par fenêtres de 15 min alignées horloge (snapshot `stopTargetMl`, report < 30 s, pas de rattrapage J+1, exemption `cyclesToday`, horizon minuit en continu ; alternatives écartées : PID slow imbriqué, fenêtres relatives au début de plage, rattrapage J+1, fenêtre 30 min, limite de cycles dédiée, recalcul continu sans snapshot). Note de renvoi ajoutée dans [ADR-0002](docs/adr/0002-mode-programmee-volume-quotidien.md).
- `docs/subsystems/pump-controller.md` : §Mode scheduled réécrit (algorithme pur + coquille, ring consulté, exemption `cyclesToday` justifiée, nouveaux logs edge-triggered, `kScheduledWindowMinutes`, accesseurs `get*ScheduledPlannedFlow`).
- `docs/subsystems/filtration.md` : `remainingRangeMinutes` ajouté au tableau des fonctions pures de `schedule_logic`.
- `docs/features/page-ph.md`, `page-orp.md` : mode Programmée détaillé (répartition, report, budget horaire, reliquat, nuance pompe rapide) + ligne « Débit calculé » et hint.
- `docs/API.md`, `docs/subsystems/ws-manager.md` : champs WS `ph/orp_scheduled_flow_ml_per_min`.

---

## [2.7.0] - 2026-07-04

### Firmware

- **MQTT/HA — modes de régulation commandables (feature-009)** : deux nouvelles entités Home Assistant `select` (« Mode Régulation pH », « Mode Régulation ORP », options `automatic` / `scheduled` / `manual`) permettent de changer `ph_regulation_mode` / `orp_regulation_mode` depuis HA (automatisations d'hivernage, absence longue, dashboards). Nouveaux topics de commande `{base}/ph_regulation_mode/set` et `{base}/orp_regulation_mode/set` (non retain, souscrits à la connexion) ; les topics state existants sont **inchangés** (retain, rétrocompat dashboards HA). Validation stricte de l'enum (insensible à la casse ; valeur invalide → ignorée + log `warning`), application dans `drainCommandQueue()` (loopTask, sous `configMutex`) par la **même voie que l'UI web** — miroir `ph/orp_enabled` ([ADR-0004](docs/adr/0004-mode-regulation-enum-3-valeurs.md)) — avec persistance NVS et log `info` uniquement si changement réel, puis republication immédiate de l'état (feedback HA). Un changement pendant une injection en cours ne l'interrompt pas : le nouveau mode prend effet au cycle de régulation suivant (validé pool-chemistry). L'UI web reste la source principale et reflète un changement initié par HA via les canaux existants (WS + `/get-config`) — aucun code UI ajouté.

### Documentation

- `docs/MQTT.md` : 2 entités `select` mode de régulation (discovery, state/command topics, options) + topics de commande ajoutés aux tableaux ; nouvelle section de détail feature-009.
- `docs/features/page-ph.md`, `page-orp.md` : tableau « Interaction MQTT » complété — mode commandable depuis HA, UI web source principale, reflet via WS.
- `docs/subsystems/mqtt-manager.md` : nouveaux `InboundCmdType::PhRegulationMode` / `OrpRegulationMode`, comportement du handler (validation, miroir ADR-0004, persistance conditionnelle, feedback `publishTargetState()`, logs), cas valeur invalide.

---

## [2.6.0] - 2026-07-04

### Firmware

- **Sécurité — injections manuelles gardées (feature-006)** : les injections manuelles (`POST /ph/inject/start`, `POST /orp/inject/start`) sont désormais soumises aux mêmes limites de sécurité chimique que la régulation automatique — limite journalière **prédictive** (cumul + volume demandé, avec reliquat dans le refus), limite horaire (**budget partagé** avec la régulation auto, [ADR-0020](docs/adr/0020-budget-horaire-dosage-unique.md) : le manuel n'était auparavant ni vérifié ni **compté**, permettant jusqu'à 2× le budget/heure), stabilisation post-calibration (par pompe), refus de double démarrage, cycles/jour et anti-rafale (ring **partagé** avec l'auto). Décision extraite en fonction pure testable `evaluateManualInject()` (`dosing_logic`, pattern ADR-0017 ; ordre des gardes et frontières `==` acceptées validés pool-chemistry ; 17 tests natifs dédiés, 135 au total, couverture `dosing_logic` 100 %). Tout refus retourne **409 JSON structuré** `{"error","message","seconds_remaining"?,"remaining_ml"?}` (8 codes) ; la garde filtration des routes de test `/pumpN/on` migre au même format. Les pompes test et commandes UART consomment aussi le budget horaire partagé. `inject/stop` reste un coupe-circuit jamais gardé.
- **fix(limites)** : le drapeau « limite journalière atteinte » (`ph/orp_limit_reached` — badges UI, blocage du bouton d'injection, alarme UART, MQTT) était **verrouillé jusqu'à minuit** : augmenter la limite journalière en cours de journée débloquait bien le dosage réel (gardes en valeurs vives) mais l'UI restait bloquée sur « limite atteinte ». Le drapeau suit désormais la condition vive et se lève dès que `cumul < limite` (limite augmentée ou compteurs réinitialisés) — validé pool-chemistry (indicateur miroir, les gardes bloquantes étaient déjà vives).

### Frontend

- **Injection manuelle — refus détaillés dans l'UI (feature-006)** : toast rouge français par code de refus (reliquat affiché pour `daily_limit`, compte à rebours pour `stabilization_in_progress`) ; bouton « ▶ Injecter » **désactivé proactivement** avec raison en hint (`#ph|orp_inject_block_hint`) quand le blocage est connu côté client (limite journalière, stabilisation, filtration arrêtée). Le firmware reste l'autorité (WS déconnecté → bouton cliquable). Le bouton « ⏹ Arrêter » n'est jamais désactivé.

### Documentation

- Nouvel [ADR-0020](docs/adr/0020-budget-horaire-dosage-unique.md) : budget horaire de dosage unique partagé auto + manuel (alternative « compteur séparé » écartée ; prédicat safety-tracking → pompes test/UART comptent aussi).
- `docs/API.md` : sections `/ph|orp/inject/start` réécrites — tableau des 8 codes de refus 409 JSON, note `/pumpN/on`.
- `docs/features/page-ph.md`, `page-orp.md` : avertissements « limites volumétriques non gardées » retirés (obsolètes) ; gardes, toasts par code et blocage proactif du bouton documentés.
- `docs/subsystems/pump-controller.md` : nouvelle section « Gardes des injections manuelles » (ordre des 9 gardes, frontières figées, budget horaire partagé, pending atomique, asymétrie stabilisation auto/manuel, note bypass UART `pump_test`).

---

## [2.5.2] - 2026-07-04

### Fonctionnalités

- **Infos système — ligne « Firmware (flash) » (feature-047)** : la carte Infos système (Paramètres → Système) affiche l'occupation de la partition app active au format `X KB / Y KB (Z%)` (taille du binaire / taille de la partition OTA courante), au même format que la ligne FS. Rend visible la marge flash gagnée par le repartitionnement layout v3 ([ADR-0019](docs/adr/0019-partition-app-1664k.md)). Côté API, `GET /get-system-info` expose un nouveau champ `sketch_size` (octets, `ESP.getSketchSize()`) ; le champ `ota_partition_size` existait déjà. Affichage `—` si les champs sont absents (compatibilité ancien firmware).

### Documentation

- `docs/API.md` : champs `sketch_size` et `ota_partition_size` ajoutés à l'exemple de `/get-system-info`.
- `docs/features/page-settings.md` : ligne « Firmware (flash) » documentée dans la carte Infos système.

---

## [2.5.1] - 2026-07-04

### Fonctionnalités

- **Paramètres — réorganisation des onglets Système / Avancé (feature-046)** : la carte « Infos système » (Firmware, Build, Uptime, Chip, CPU, Heap libre, Flash, FS, Wi-Fi RSSI, MAC + bouton Actualiser) est **déplacée** de l'onglet Avancé vers la **première position** de l'onglet Système ; la carte « Version du firmware », redondante, est **supprimée** de l'onglet Système (la version reste visible sur la ligne « Firmware » d'Infos système) ; la carte « Historique des mesures (température, pH, ORP) » (export/import/suppression CSV) est **déplacée** de l'onglet Système vers la **première position** de l'onglet Avancé. Frontend uniquement — aucun changement backend (`GET /get-system-info`, `/get-history`, `/history/import`, `/history/clear` inchangés).

### Documentation

- `docs/features/page-settings.md` : contenu des onglets Système et Avancé mis à jour (Infos système en tête de Système, Historique des mesures en tête d'Avancé, position de la card Diagnostic crash dans Avancé).

---

## [2.5.0] - 2026-07-04

### Firmware

- **Retrait des outils de diagnostic d'oscillation pH (feature-045)** : les trois outils ajoutés pour la campagne de diagnostic 2026-05/06, devenus inutiles en exploitation, sont supprimés :
  - **Debug oscillation pH** : carte UI du panel Avancé + ring buffer 300 échantillons (~6 KB RAM) + routes `GET /debug/ph_trace` et `POST /debug/ph_trace_clear` ;
  - **Pause WiFi** : routes `GET`/`POST /debug/wifi_pause` + mécanisme de pause associé ;
  - **Diagnostic EZO** : carte UI + routes `POST /debug/ezo_command` et `POST /debug/ezo_factory`.

  Les 5 routes répondent désormais **404**. Gains mesurés : **Flash −12 272 o**, **RAM statique −6 024 o**, **payload FS minifié −13 809 o**. Restent en place : `/debug/ph_slope_refresh`, `/debug/sensor_filter_reset`, `/debug/sensor_filter_state` (levier de sécurité feature-025) et les routes coredump.

  > **Réintégration** : code récupérable via `git revert` du commit de la feature-045 ; état complet avec les outils figé au tag `v2.4.0`.

### Documentation

- `docs/API.md` : sections « Diagnostic Atlas EZO » et `ph_trace`/`ph_trace_clear` retirées, remplacées par une note « Routes de debug supprimées (v2.5.0) ».
- `docs/features/page-settings.md` : cartes « Debug oscillation pH » et « Diagnostic EZO » retirées du panel Avancé (note de réintégration ajoutée).
- `docs/BUILD.md` : décompte des graphiques uPlot ramené à 6 (le chart debug oscillation est retiré).

---

## [2.4.0] - 2026-07-04

### Firmware

- **Repartitionnement flash — layout v3 (feature-044)** : les slots firmware `app0`/`app1` passent de 1536 à **1664 KB** (+128 KB chacun), pris sur la partition `spiffs` réduite de 832 à **576 KB** (offset déplacé à `0x350000`) — rendu possible par la migration uPlot (feature-043, payload FS 449 KB). Occupation firmware : 90,8 % → **83,8 %** (1 427 753 / 1 703 936 o, marge ~270 KB) ; FS à ~82 % de 576 KB (marge ~104 KB). Partitions `nvs`, `history` et `coredump` strictement inchangées : **config, historique et coredump préservés**. ⚠️ **Mise à jour par câble USB requise une seule fois** (`./deploy.sh all`) — l'OTA ne peut pas réécrire la table de partitions ; ne pas utiliser `./deploy.sh factory` (efface la NVS). L'OTA redevient normal ensuite. Fichiers alignés : `partitions.csv`, `platformio.ini` (`filesystem_size = 589824`), `build_fs.sh`, `deploy.sh`.
- **`deploy.sh`** : correction du check de taille de `littlefs.bin` resté au layout v1 (1 114 112 → 589 824 octets) — il déclenchait à tort une reconstruction du FS à chaque upload.

### Documentation

- Nouvel [ADR-0019](docs/adr/0019-partition-app-1664k.md) : partitions app à 1664 KB (layout v3) — contexte (app0 à 90,8 %, gains `CORE_DEBUG_LEVEL` −33 KB et uPlot −148 KB FS), alternatives écartées (palier +64 KB conservateur ; +192 KB impossible, FS à 100 %), conséquences (flash USB unique, données préservées). [ADR-0015](docs/adr/0015-partition-app-1.5mb.md) marqué « Superseded by ADR-0019 ».
- `docs/BUILD.md` : taille filesystem 589 824 o = 576 KB (layout v3, ADR-0019), piège « changement de table = flash USB », occupation firmware actualisée.
- `docs/UPDATE_GUIDE.md` : nouvelle note « Migration layout v2 → v3 (v2.4.0) » — procédure USB, préservé/réécrit, avertissement `factory`.

---

## [2.3.0] - 2026-07-04

### Frontend

- **Graphiques — migration Chart.js → uPlot (feature-043)** : la bibliothèque de graphiques passe de Chart.js v4.5.1 (`chart.umd.min.js`, ~208 KB, **supprimé**) à **uPlot 1.6.32** (`uPlot.iife.min.js` + `uPlot.min.css`, paquet npm `uplot@1.6.32` figé, committés dans `data/` — offline, sans bundler). **Rendu à parité stricte** sur les 7 graphiques (3 mini-charts dashboard avec coloration conditionnelle par segment et dégradé de remplissage, 3 historiques détail pH/ORP/Température avec bandes min/max, 1 debug oscillation multi-axes avec séries masquées par défaut) : labels X catégoriels (« Aujourd'hui », mois français, `HH:MM`, `-Ns`), tooltip, boutons de plage synchronisés, gel pendant calibration et polling incrémental 5 min conservés. **Payload FS réduit de −148,3 KB** (601 054 → 449 177 octets, ≈ 449 KB / partition `spiffs` 832 KB) — prépare le repartitionnement `app0`/`app1`. Les options mortes de l'ancienne usine `createLineChart` (`hideYAxis`, `showYAxisGrid`, `extraPlugins`, `annotation`, `backgroundColor`) ne sont pas reprises.

### Documentation

- Nouvel [ADR-0018](docs/adr/0018-migration-uplot.md) : uPlot au lieu de Chart.js (contrainte Flash/FS — alternatives Chart.js slim et statu quo écartées).
- `docs/BUILD.md` : nouvelle section « Bibliothèque de graphiques uPlot » (provenance npm `uplot@1.6.32` figé, procédure de mise à jour manuelle, gain mesuré, options non reprises) + correction de la taille de la partition `spiffs` (832 KB, layout v2 — la mention 1088 KB était obsolète).
- `docs/features/page-dashboard.md`, `page-ph.md`, `page-orp.md`, `page-temperature.md`, `page-settings.md` : mentions Chart.js remplacées par uPlot.

---

## [2.2.11] - 2026-06-27

### Firmware

- **Refactor interne (feature-041) — math d'agrégation de l'historique testable** : la math **scalaire** d'agrégation est extraite de `history.cpp::consolidateData()` vers le module **pur** `src/history_logic.{h,cpp}` (headers C uniquement `<stdint.h>`/`<math.h>`, sans `<vector>`/`<map>`/Arduino/FreeRTOS, pattern *Humble Object*) : `bucketTimestamp` (troncature au bucket horaire/quotidien, garde `bucketSeconds==0`), `isOlderThan` (prédicat d'ancienneté `(now-ts) > maxAge`, frontière **stricte**, wrap `uint32` conservé), `finalizeMean` (moyenne, `count==0` → `NaN`), `isMajority` (majorité stricte `> total/2`, division entière), `anyTrue` (`>0`). Les deux passes (raw → horaire, horaire → quotidien) **délèguent** ; le regroupement `std::map`/`std::vector`, l'accumulation et la persistance restent dans la coquille. *Characterization refactor* : **aucun changement de comportement** (frontières strictes, divisions entières et wrap reproduits à l'identique — revue **Approved**). Aucun comportement visible utilisateur, aucun endpoint / WS / MQTT touché.

### Tests

- **25 tests Unity natifs** (feature-041) couvrant la math d'agrégation : troncature au bucket (garde division par zéro), prédicat d'ancienneté (frontière `==`, wrap post-`0xFFFFFFFF`), moyenne (`count==0` → `NaN`), majorité stricte (`2/4`, `3/4`, `3/5`) et `anyTrue`. `history_logic.cpp` couvert à **100 % des lignes** (**118 tests au total**). `coverage.sh` et `build_src_filter` étendus au nouveau module. Le regroupement `std::vector`/`std::map` de `consolidateData()` reste **hors tests natifs** (contrainte libc++ absente en natif).

### Documentation

- `docs/subsystems/history.md` : nouvelle section « Math d'agrégation pure (`history_logic`) » — les 5 fonctions pures, leurs frontières (strictes, divisions entières, wrap `uint32`, `NaN`), la délégation des deux passes, et la note explicite que le regroupement `std::vector`/`std::map` reste hors tests natifs. Réutilise [ADR-0017](docs/adr/0017-logique-metier-pure-humble-object-testabilite.md) (Humble Object) — **pas de nouvel ADR**.

---

## [2.2.10] - 2026-06-27

### Firmware

- **Refactor interne (feature-040) — logique d'horaire de l'éclairage testable** : la décision d'horaire de l'éclairage est extraite de `lighting.cpp` vers le module **pur** `src/schedule_logic.{h,cpp}` (créé en feature-038, **réutilisé** ici). Nouvelle fonction `decideLightingOn(manualOverride, enabledFlag, scheduleEnabled, haveTime, nowMin, startMin, endMin, currentlyOn)` ; `isMinutesInRange` gagne un 4ᵉ paramètre `bool equalMeansAlways = false`. La divergence `start == end` entre les deux domaines est **intentionnellement préservée** : filtration → `false` (plage invalide, jamais) ; éclairage → `true` (allumé toute la journée). `lighting.cpp::update()` devient une coquille mince déléguant ; RTC/`millis()`/`digitalWrite`/`publishState`/MQTT restent dans la coquille. *Characterization refactor* : **aucun changement de comportement** (ni éclairage ni filtration — la valeur par défaut `false` garantit la non-régression de la filtration). Aucun comportement visible utilisateur, aucun endpoint / WS / MQTT touché.

### Tests

- **11 nouveaux tests Unity natifs** (feature-040) couvrant la décision d'horaire éclairage : équivalence stricte de `decideLightingOn`, divergence `start == end` (éclairage → `true`, filtration → `false`), fenêtre simple et fenêtre franchissant minuit, priorités manuel/horaire, conservation de l'état quand l'heure est indisponible. `schedule_logic.cpp` reste couvert à **100 % des lignes** (**93 tests au total**).

### Documentation

- `docs/subsystems/lighting.md` : nouvelle section « Logique d'horaire pure (`schedule_logic`) » — `decideLightingOn`, paramètre `equalMeansAlways`, divergence intentionnelle `start==end` (filtration `false` / éclairage `true`), non-régression filtration, testabilité native. Réutilise [ADR-0017](docs/adr/0017-logique-metier-pure-humble-object-testabilite.md) (Humble Object) — **pas de nouvel ADR**.
- `docs/subsystems/filtration.md` : la ligne `isMinutesInRange` documente le 4ᵉ paramètre `equalMeansAlways` et la divergence éclairage.

---

## [2.2.9] - 2026-06-27

### Firmware

- **Refactor interne (feature-039) — anti-rafale & rollover journalier testables** : la logique d'**anti-rafale** du dosage (comptage de cycles sur fenêtres glissantes 1 min / 15 min via ring buffer, gestion du **wrap `millis()`** en `uint32_t`, écriture circulaire) et les **déclencheurs de rollover journalier** (reset des quotas à minuit date NTP / fallback 24 h) sont extraits de `pump_controller.cpp` vers le module **pur** `src/dosing_logic.{h,cpp}` : `countCyclesInWindow`, `recordCycleTimestamp`, `shouldRolloverByDate`, `shouldRolloverByMillis` — sans dépendance Arduino / `millis()` / `time()` / NVS / état membre, donc **testables en natif**. Les méthodes `recordDosingCycleStart` / `countRecentDosingCycles` / `tickDailyRollover` deviennent des coquilles minces (fournissent `millis()` / `time()` / les buffers et délèguent ; `localtime_r`/`strftime`, écriture `safetyLimits`, `saveDailyCounters`, `armStabilizationTimer`, logs et branche première-init restent dans la coquille). *Characterization refactor* : **seuils et frontières strictement préservés** (6 cycles/min, 20 cycles/15 min, ring buffer 20, rollover 24 h) — la garde anti-emballement de `canDose()` (#14/#15) et le reset des quotas sont inchangés (équivalence stricte validée par `pool-chemistry`, 2 passages). Aucun comportement visible utilisateur.

### Tests

- **15 nouveaux tests Unity natifs** (feature-039) couvrant l'anti-rafale et le rollover : comptage en fenêtre glissante (buffer vide, slots à 0, `ts` dans/hors fenêtre, `ts == now`, **wrap `millis()` post-`0xFFFFFFFF`**), écriture circulaire du ring buffer (avance d'index, écrasement du plus ancien), déclencheurs de rollover par date (vide / identique / différente) et par fallback 24 h (frontière `== 86400000`, wrap). `dosing_logic.cpp` couvert à **100 % des lignes** (**85 tests au total**).

### Documentation

- `docs/subsystems/pump-controller.md` : nouvelle section « Anti-rafale & rollover journalier (logique pure) » — les 4 fonctions pures, comptage wrap-safe `uint32_t`, déclencheurs de rollover (date NTP / fallback 24 h), coquilles `pump_controller` qui délèguent, comportement strictement préservé, testabilité native. Réutilise [ADR-0017](docs/adr/0017-logique-metier-pure-humble-object-testabilite.md) (Humble Object) — **pas de nouvel ADR**.

---

## [2.2.8] - 2026-06-27

### Firmware

- **Refactor interne (feature-038) — logique d'horaire de filtration testable** : la décision d'horaire de `filtration` (parsing `"HH:MM"` `timeStringToMinutes`, appartenance à une fenêtre `isMinutesInRange` gérant le passage minuit, calcul du créneau auto selon température `computeAutoWindow` — durée = temp/2 bornée `[1,24]`, centrée sur `kFiltrationPivotHour`, wrap des bornes dans `[0,24)` —, et décision marche/arrêt `decideFiltrationRun` avec priorités **`forceOn` > `forceOff` > plage** et **conservation de l'état si l'heure est indisponible**) est extraite vers un module **pur** `src/schedule_logic.{h,cpp}` (pattern *Humble Object*), sans dépendance Arduino / RTC / `millis()` / NVS / FreeRTOS — donc **testable en natif**. Module **générique**, réutilisable pour l'éclairage. `update()` / `begin()` / `computeAutoSchedule()` deviennent des coquilles minces ; RTC, `millis()`, NVS, deadband 1 °C, timeout 4 h, stabilisation et commande relais restent dans la coquille. *Characterization refactor* : **aucun changement de comportement** (équivalence stricte validée par `pool-chemistry`, dont la préservation de la garde « présence d'eau » de `canDose()`). Aucun comportement visible utilisateur.

### Tests

- **19 nouveaux tests Unity natifs** (feature-038) couvrant la décision d'horaire : parsing `"HH:MM"` (cas invalides inclus), appartenance à une fenêtre traversant minuit, créneau auto borné/centré, priorités des forçages et conservation de l'état sans heure valide. `schedule_logic.cpp` couvert à **100 % des lignes** (**70 tests au total**).

### Documentation

- `docs/subsystems/filtration.md` : nouvelle section « Logique d'horaire pure (`schedule_logic`) » — les 4 fonctions pures, décision/priorités, temps indisponible → conservation d'état, fenêtre auto centrée et wrap minuit, testabilité native, coquilles `update()`/`begin()`/`computeAutoSchedule()`. Réutilise [ADR-0017](docs/adr/0017-logique-metier-pure-humble-object-testabilite.md) (Humble Object) — **pas de nouvel ADR** ; `schedule_logic` est un module générique partagé filtration/éclairage.

---

## [2.2.7] - 2026-06-27

### Firmware

- **Refactor interne (feature-037) — calcul proportionnel testable** : le cœur du calcul PID de `pump_controller` (terme proportionnel `kp × error`, termes `Ki`/`Kd`, anti-windup par gel/bornage de l'intégrale à `±integralMax`, plancher sortie négative → 0, **bornage final min/max**) est extrait de `computePID` vers une fonction **pure** `computePidPure` (`src/dosing_logic.{h,cpp}`), sans dépendance Arduino / `millis()` / état membre, donc **testable en natif**. L'état PID (intégrale + dernière erreur) est désormais **injecté en paramètre** et **renvoyé** via `struct PidResult`. Le `constrain` de débit qui était appliqué chez les appelants pH/ORP est déplacé **dans la fonction pure** (« Option Y ») : `computePidPure` renvoie le débit **final borné**, et `computePID` ainsi que les deux chemins pH/ORP deviennent des coquilles minces (gestion du temps + état uniquement). `computeFlowFromError` reste du code mort (non extrait). *Characterization refactor* : **les débits calculés et l'évolution de l'intégrale sont strictement préservés** (équivalence stricte validée par `pool-chemistry`). Aucun comportement visible utilisateur.

### Tests

- **Tests Unity natifs étendus (feature-037)** : couverture **100 % des lignes** de `computePidPure` (21 tests et plus) — terme proportionnel, gel de l'intégrale, bornage anti-windup `±integralMax`, plancher 0, bornage final min/max. Le temps et l'état PID étant injectés, chaque branche est exercée sans matériel ni attente réelle. `pio test -e native` continue de couvrir les suites `test/test_native_sensor_filter/` + `test/test_native_dosing/`.

### Documentation

- `docs/subsystems/pump-controller.md` : nouvelle section « Calcul proportionnel pur (`computePidPure`) » — fonction pure, état PID injecté/renvoyé (`PidResult`), bornage final intégré (« Option Y »), testabilité native 100 %, `computePID` et chemins pH/ORP réduits à des coquilles. Réutilise [ADR-0017](docs/adr/0017-logique-metier-pure-humble-object-testabilite.md) (Humble Object) — **pas de nouvel ADR**.

---

## [2.2.6] - 2026-06-27

### Firmware

- **Refactor interne (feature-036) — décision de dosage testable** : la logique de décision « peut-on doser ? » de `pump_controller` est extraite dans un module **pur** `src/dosing_logic.{h,cpp}` (pattern *Humble Object*), sans dépendance Arduino / FreeRTOS / I²C, donc **testable en natif**. `canDose()` devient une coquille mince qui collecte les globals, délègue à `evaluateDose(DoseInputs) → DoseDecision`, puis mappe l'énum de cause vers la chaîne française exposée (valeurs runtime réinjectées). *Characterization refactor* : **aucun seuil, verdict, cause de refus ni ordre d'évaluation des gardes n'a changé** (équivalence stricte validée par `pool-chemistry`). Hystérésis de démarrage/arrêt et temps minimum d'injection également exposés en fonctions pures (`shouldStartDosingPure` / `shouldContinueDosingPure`, temps injecté). Aucun comportement visible utilisateur.

### Tests

- **21 nouveaux tests Unity natifs** (feature-036) couvrant la décision de dosage : chaque cause de refus de `evaluateDose`, l'hystérésis start/stop aux bornes (deadband), et un **verrou de non-régression** du bug pause-mélange v2.2.5 (une injection auto dure ≥ `minInjectionTimeMs` avant l'armement de la pause). `pio test -e native` couvre désormais deux suites (`test/test_native_sensor_filter/` + `test/test_native_dosing/`).

### Documentation

- `docs/subsystems/pump-controller.md` : nouvelle section « Décision de dosage : logique pure (`src/dosing_logic`) vs coquille hardware » (frontière POD/String, table énum `DoseRefusal` ↔ cause FR, fonctions pures). Correction d'une imprécision préexistante : limite horaire évaluée avec `>=` (et non `>`).
- `docs/BUILD.md` : section « Tests natifs (hors matériel) » — `pio test -e native` couvre deux suites, `build_src_filter` inclut `sensor_filter.cpp` + `dosing_logic.cpp`.
- `docs/adr/0017-logique-metier-pure-humble-object-testabilite.md` : nouvel ADR « Logique métier pure (Humble Object) séparée de la couche hardware pour testabilité native » (lié à ADR-0016 et feature-025).

---

## [2.2.5] - 2026-06-23

### Firmware

- **Corrections — régulation pH/ORP auto** : la pause mélange hydraulique (15 min pH / 20 min ORP, feature-025) était armée par erreur **au démarrage** de l'injection. Conséquence : la garde `canDose()` (« pause mélange en cours », #5b/#6b) sautait la branche de régulation au cycle `update()` suivant, coupant la pompe après ~un cycle de boucle. Les injections automatiques ne duraient jamais le minimum prévu (`minInjectionTimeMs` = 30 s) → régulation inefficace (le pH/ORP ne convergeait pas vers la cible, chip « Mélange en cours » affiché en continu). La pause est désormais armée à l'**arrêt** de l'injection (homogénéisation post-dose) : `notifyPhDose()` / `notifyOrpDose()` sont appelés quand l'injection en cours se termine, sans interrompre celle-ci. `minInjectionTimeMs` et `shouldContinueDosing` sont de nouveau effectifs. Bug introduit par feature-025 ; **fail-safe** (sous-dosage, aucun risque de surdosage).

### Documentation

- `docs/subsystems/pump-controller.md` : section « Pause mélange hydraulique » corrigée — pause armée à l'arrêt de l'injection (et non au démarrage), interaction avec `minInjectionTimeMs` / `shouldContinueDosing` précisée.

---

## [2.2.4] - 2026-06-23

### Fonctionnalités

- **Uniformisation de l'écran Température** (feature-035) : l'écran Température adopte le même agencement que pH/ORP — un **bloc « stats » en haut** (valeur courante + **chip d'état de calibration** + bouton **« Calibrer la sonde »**), et une **carte de calibration masquée** qui s'affiche au clic (masque les cartes Activation + Historique, bouton **Fermer** pour revenir). La calibration reste **par offset 1 point** (saisie d'une température de référence connue → offset, via `/save-config`) : logique inchangée. Le chip affiche « Calibré · aujourd'hui / il y a N j / le JJ/MM » (vert), « Calibré · ancien (il y a N mois) » si > 6 mois (ambré), ou « Non calibré » (gris). La lecture live de la température reste visible pendant la calibration (pas d'indicateur de stabilité — température lente). Les anciens callouts (`#temp_cal_date_header` / `#temp_calibrated_status`) sont **supprimés** au profit du chip.
- **Désactivation de la sonde** (feature-035) : décocher l'activation masque désormais correctement la carte du tableau de bord ainsi que les blocs stats/historique/calibration de la page Température (la carte d'activation reste accessible pour réactiver).

### Documentation

- `docs/features/page-temperature.md` : réécriture pour le nouvel agencement (feature-035) — bloc stats (valeur + chip de calibration), bouton « Calibrer la sonde », carte de calibration masquée (stepper offset + lecture live + Fermer), états du chip, données consommées et cas limites.

---

## [2.2.3] - 2026-06-23

### Fonctionnalités

- **Calibration guidée pH/ORP accessible dans tous les modes** (feature-034) : la calibration des sondes pH et ORP est désormais accessible quel que soit le mode de régulation (**automatique, programmée, manuelle**) — auparavant limitée au mode automatique. Le mode en cours est **conservé** à la sortie de la calibration (plus de bascule forcée en automatique).
- **Écran de calibration guidé** (feature-034) : nouvel accompagnement par **stepper** avec états visuels (étape faite ✓ / en cours / restante, `aria-current`), **minuterie de stabilisation** par étape d'attente (compte à rebours 60 s, non bloquant — on peut calibrer avant la fin), et **indicateur de stabilité Δ60 s** (amplitude max−min de la mesure brute, purement indicatif). Le readout reste la valeur **brute** (feature-025, non régressé).
- **Sécurité (feature-034)** : le bouton « Calibrer » est désormais aussi bloqué pendant une **injection pH** en cours (le garde n'existait que côté ORP).
- **Chip d'état de calibration** (feature-034, itération 2) : sur les pages pH et ORP, l'état de calibration est désormais résumé par un **chip** dans la rangée de chips (à côté des chips sonde et filtre) — états « Calibré 2/2 » (pH) / « Calibré » (ORP) en vert, « Calibration 1/2 » en ambré (pH partiel), « Calibration requise » en rouge (régulation auto inhibée), « EZO indisponible » en gris, et « Calibration — » tant que les données ne sont pas reçues. Les **3 anciens callouts** (calibré / régulation inhibée / EZO injoignable) sont **supprimés** ; leur information est portée par le chip + un hint texte.
- **Bouton « Calibrer la sonde » repositionné** (feature-034, itération 3) : sur les pages pH et ORP, le bouton de calibration est désormais affiché **sous la rangée de chips** (dans le bloc Statistiques) avec un **libellé fixe « Calibrer la sonde »** (remplace les libellés adaptatifs « Calibrer » / « Continuer la calibration » / « Recalibrer » de l'itération 2). L'état de calibration reste porté par le chip + le hint. Les blocs `#ph-calibration-info` / `#orp-calibration-info` en bas de la carte de régulation sont **retirés**. Le bouton reste **toujours accessible** dans tous les modes (recalibration possible) et **désactivé** pendant une injection en cours.
- **Chip pH unique « sonde + calibration »** (feature-034) : sur la page pH, le chip de calibration séparé est **supprimé** ; son information est **fusionnée** dans le chip sonde (`#ph-probe-chip`) pour lever la redondance. Le chip pH affiche « EZO indisponible » (gris) si EZO injoignable, « Calibration requise » (rouge) si 0 point, « Calibration 1/2 » (ambré) si 1 point, et le **diagnostic de pente** habituel (« Sonde excellente / correcte / usée / à remplacer · N% ») dès 2 points calibrés. La page ORP conserve son chip de calibration dédié (pas de chip sonde côté ORP). Le bouton « Calibrer la sonde » et son hint restent inchangés.

### Documentation

- `docs/features/page-ph.md` / `docs/features/page-orp.md` : calibration accessible tous modes, écran guidé (stepper d'états, minuterie de stabilisation, indicateur de stabilité Δ60 s), garde injection, **chip d'état de calibration** remplaçant les callouts (itération 2), et **bouton « Calibrer la sonde »** repositionné sous les chips avec libellé fixe (itération 3, volet A ; volet B « calibration périmée » abandonné).
- `docs/subsystems/sensors.md` : précision que le reset filtre + warmup post-calibration est **mode-indépendant** (déclenché par le succès EZO).

---

## [2.2.2] - 2026-06-21

### Firmware

- **fix(sensors)/tune** : délai de re-synchronisation du filtre réduit de ~2 min à ~1 min (feature-033) — `kSensorFilterResyncRejects` 24 → 12. Invariant fail-closed préservé (12 > 10 instable, 12 > 7 fenêtre médiane).

### Documentation

- `docs/subsystems/sensors.md` : seuil et délai de re-synchronisation (24 → 12, ~120 s → ~60 s).

---

## [2.2.1] - 2026-06-20

### Firmware

- **fix(sensors)** : correction du gel de la valeur filtrée après immersion en solution de calibration (re-synchronisation + anti-boucle). Un changement réel et durable au-delà de `maxStep` (ex. sonde plongée en solution puis retour en bassin) figeait `filtered` à vie → dosage bloqué en permanence. Le filtre se ré-amorce désormais sur la médiane des bruts rejetés après `kSensorFilterResyncRejects` (= 24, ≈ 120 s) rejets consécutifs, puis repart en warmup. Anti-boucle EMI : au-delà de `kSensorFilterMaxResyncPerWindow` (= 3) re-sync sur `kSensorFilterResyncWindowMs` (= 10 min), le capteur est déclaré instable de façon **latchée** jusqu'à un `reset()` explicite (`POST /debug/sensor_filter_reset` ou calibration réussie). Gardes `canDose()` inchangées.

### Fonctionnalités

- **fix(calibration)** : le readout live de calibration pH/ORP affiche la valeur brute (la valeur lissée figeait l'affichage en changeant de solution étalon).

### Documentation

- `docs/subsystems/sensors.md` : sections re-synchronisation (latch-up résolu) et anti-boucle latché, 3 nouvelles constantes, getters `resyncCount()` / `unstableLatched()`, levée du latch par `reset()`.

---

## [2.2.0] - 2026-06-16

### Fonctionnalités

- **Lissage des mesures pH/ORP** (feature-025) : les pages pH et ORP affichent désormais la valeur **filtrée** (médiane glissante + moyenne exponentielle) en grand, avec une ligne discrète « brut · médiane · maj » pour le diagnostic. Un **chip d'état filtre** à 5 états (`Stabilisation…` / `Mesure stable` / `Pics rejetés` / `Capteur instable` / `EZO indisponible`) résume la santé de la chaîne de mesure ; un clic ouvre un modal détail (brut/médiane/filtré, rejets, âge, raison de blocage du dosage).
- **Debug oscillation pH** : la courbe de diagnostic du panel Avancé trace désormais **deux séries pH** — « pH brut » (bleu) et « pH lissé » (orange) — sur le même axe, avec une ligne de stats « pH lissé min / max / Δ » en complément du brut. Permet de visualiser l'effet du filtre feature-025. Le payload de `GET /debug/ph_trace` expose le nouveau champ `phFiltered` par échantillon.

### Firmware

- **Filtrage capteurs** (feature-025) : nouvelle chaîne `mesure brute Atlas EZO → rejet aberrants → médiane (fenêtre 7) → EMA (alpha pH 0.10 / ORP 0.08) → valeur filtrée`. Classe dédiée `SensorFilter` déterministe (buffer fixe, testable hors matériel). Valeurs brutes conservées pour diagnostic EMI. Filtre réinitialisé (warmup) après calibration pH/ORP réussie. Paramètres centralisés dans `constants.h` (`kSensorFilter*`, `kPhEmaAlpha`, `kOrpEmaAlpha`, plages plausibles, seuils de rejet).
- **Régulation P temporisée** (feature-025, [ADR-0016](docs/adr/0016-regulation-p-temporisee-vs-pid.md)) : le PID consomme désormais la mesure **filtrée et prête** (jamais la brute). Stratégie par défaut proportionnelle pure (`Kp` pH=8 / ORP=0.3, `Ki=0`, `Kd=0` impératif). Anti-windup strict, zone morte = seuil de démarrage, nouvelles gardes `canDose()` fail-closed (filtre non prêt, capteur instable, pause mélange).
- **Pause mélange hydraulique** (feature-025) : après chaque injection, blocage de toute nouvelle décision de dosage le temps de l'homogénéisation du bassin — `kPhMixingDelayMs = 15 min`, `kOrpMixingDelayMs = 20 min` (gérée par timestamps, pas de `delay()`).
- **MQTT** : nouveaux topics retain `{base}/ph|orp_raw|median|filtered|filter_ready|filter_unstable|rejected_count` + `{base}/ph|orp_mixing_delay_active`. Les topics `{base}/ph` et `{base}/orp` publient désormais la valeur filtrée. Auto-discovery HA : sensors « pH/ORP Brut » et « pH/ORP Filtré » + binary_sensors « Filtre pH/ORP Prêt ».

### API

- **WebSocket / `GET /data`** : champs `phRaw/phMedian/phFiltered/phFilterReady/phFilterUnstable/phRejectedCount/phMixingDelayActive/phDoseBlockedReason` (+ équivalents `orp*`). `ph` / `orp` correspondent désormais à la valeur **filtrée** (fallback brut tant que le filtre n'est pas amorcé).
- **`POST /debug/sensor_filter_reset`** : réinitialise les deux filtres (warmup). **`GET /debug/sensor_filter_state`** : état JSON brut des filtres.

### Documentation

- `docs/subsystems/sensors.md` : chaîne de filtrage, classe `SensorFilter`, paramètres, reset après calibration, états warmup/unstable.
- `docs/subsystems/pump-controller.md` : entrée PID filtrée, régulation P temporisée, anti-windup, zone morte, pause mélange, nouvelles gardes `canDose()`.
- `docs/MQTT.md` / `docs/API.md` : nouveaux topics, champs WS et endpoints debug.
- `docs/features/page-ph.md` / `docs/features/page-orp.md` : affichage filtré/brut, chip d'état filtre, modal détail.
- `docs/features/page-settings.md` / `docs/API.md` : card « Debug oscillation pH » à 2 courbes (brut + lissé), champ `phFiltered` du payload `GET /debug/ph_trace`.
- **ADR-0016** créé : régulation P temporisée par défaut (Kp seul, Ki=0, Kd=0) sur mesure filtrée vs PID complet.

---

## [2.1.2] - 2026-05-10

### Sécurité chimique

- **Garde filtration sur l'injection manuelle** — bug observé en production : injection manuelle volumée pH lancée pendant filtration active continuait après l'arrêt programmé de la filtration → surdosage local d'acide dans la zone du retour d'eau (pas de circulation). Refonte de [`src/web_routes_control.cpp`](src/web_routes_control.cpp) avec deux mitigations :
  - **Refus en amont (HTTP 409)** — helper privé `injectionAllowedOrReject(req, tag)` appelé en début des handlers `/ph/inject/start`, `/orp/inject/start`, `/pump1/on`, `/pump2/on`. Vérifie `mqttCfg.regulationMode == "continu" || filtration.isRunning()` (même critère que `PumpController::canDose()`, cohérence des deux gardes). Refus = HTTP `409 Conflict` avec corps texte explicite. Les handlers d'arrêt (`/ph/inject/stop`, `/orp/inject/stop`, `/pump[12]/off`) restent **inconditionnels** — pouvoir arrêter en toute circonstance.
  - **Arrêt cyclique en cours d'injection** — `updateManualInject()` (appelée à chaque tour `loopTask`) interrompt l'injection si la filtration tombe pendant celle-ci. Latence < 100 ms après détection. Logue `critical("[Injection] {pH|ORP} INTERROMPUE — filtration arrêtée (sécurité chimique)")` et publie l'alerte MQTT correspondante.
- **Bornage durée injection 3600 → 600 s** — nouvelle constante `kManualInjectMaxDurationS = 600` ([`src/constants.h`](src/constants.h)) appliquée aux deux routes inject/start. Justification pool-chemistry : 3600 s trop long en cas d'arrêt filtration en milieu de cycle ; 10 min couvrent les usages typiques et l'utilisateur peut toujours relancer.
- **Pas de reprise automatique** après reprise filtration — choix produit. L'injection en cours est perdue, l'utilisateur doit relancer manuellement (toast UI explicite).

> Validation `pool-chemistry` : GO sous conditions, **toutes appliquées**. Cohérence avec la condition #3 de `canDose()` (filtration en marche sauf mode `continu`) — voir [docs/subsystems/pump-controller.md](docs/subsystems/pump-controller.md).

### API

- **`POST /ph/inject/start`, `POST /orp/inject/start`, `POST /pump1/on`, `POST /pump2/on`** : nouveau code retour **`409 Conflict`** « filtration arrêtée — injection refusée pour sécurité chimique » (sauf si `regulationMode == "continu"`). Voir [`docs/API.md`](docs/API.md).
- **`POST /ph/inject/start`, `POST /orp/inject/start`** : paramètre `duration` désormais borné à **600 s** (`kManualInjectMaxDurationS`) au lieu de 3600 s.

### MQTT

Deux nouveaux types d'alerte sur le topic existant `{base}/alerts` (QoS 0, no retain — mécanisme `mqttManager.publishAlert()` inchangé). Aucun nouveau topic, aucune nouvelle entité auto-discovery HA — l'utilisateur peut créer une automation HA sur le topic alerts.

| Type | Condition |
|---|---|
| `ph_injection_aborted` | Injection manuelle pH interrompue par la sécurité chimique (filtration arrêtée pendant injection) |
| `orp_injection_aborted` | Injection manuelle ORP/chlore interrompue par la sécurité chimique |

### Frontend

- **Refus 409 au démarrage** : `startInject(product)` dans [`data/app.js`](data/app.js) restaure le bouton et affiche un toast rouge « Injection refusée : la filtration doit être active avant d'injecter (sécurité chimique : pas de circulation = surdosage local). »
- **Interruption en cours** : `_onWsLog(entry)` détecte `entry.level === 'CRITICAL'` + message contenant `[Injection]` et `INTERROMPUE` (capté via le canal WS log existant `broadcastLog()`, pas de nouveau message WS) → toast rouge « Injection {pH|ORP/chlore} interrompue : la filtration s'est arrêtée. Relancez l'injection après reprise de la filtration. »
- **Erreurs HTTP autres** : lecture du body texte et affichage si court (< 200 chars), sinon message générique.

### Documentation

- `docs/API.md` : nouveau code 409 documenté sur les 4 routes concernées, mention du nouveau bornage `kManualInjectMaxDurationS = 600 s`, encart sur l'arrêt cyclique automatique et l'alerte MQTT émise.
- `docs/MQTT.md` : ajout des deux types d'alertes `ph_injection_aborted` et `orp_injection_aborted` dans la table des alertes.
- `docs/subsystems/pump-controller.md` : nouvel encart « Garde filtration injection manuelle » dans la section sécurité chimique, ajout de `kManualInjectMaxDurationS` au tableau des constantes.
- `docs/features/page-ph.md` et `docs/features/page-orp.md` : section comportement UI mise à jour (toasts, refus, interruption), avertissement « injection manuelle non gardée » remplacé par la documentation de la nouvelle garde filtration.

### Notes

- Aucun ADR créé : c'est une mitigation d'un bug de sécurité (ajout d'une garde manquante). Pas de contrainte structurante, pas d'alternatives crédibles à arbitrer (`pool-chemistry` impose la garde), pas de verrouillage long terme.
- Pas de spec formelle — fix réactif sur bug observé en production. Le rapport `pool-chemistry` (GO sous conditions) tient lieu de cadrage.

---

## [2.1.1] - 2026-05-10

### Firmware

- **Détection corruption LittleFS au boot** (`3c8b657`) — `HistoryManager::begin()` force maintenant un test write/read sur fichier témoin `/.fscheck` après le mount LittleFS de la partition `history`. Si l'opération échoue (open / write / read / compare KO), la partition est effacée via `esp_partition_erase_range` puis remontée propre. Garde-fou contre un bug LittleFS connu : un FS corrompu peut être monté sans erreur puis crasher en `IntegerDivideByZero` à la 1ʳᵉ écriture (observé sur ESP32 PCB v1 après une longue inactivité). Logs : warning « Partition history corrompue détectée — reformatage automatique » + info « Partition history reformatée et remontée ». ⚠️ L'historique persistant est perdu si le reformatage est déclenché. Coût négligeable en cas nominal (~10 ms, ~500 B flash).
- **Underflow uint32 dans la garde 24 h Slope query** (`933f17c`, feature-024) — `SensorManager::update()` étape 5 calculait `(now - _phSlopeQueriedMs)` avec `now` figé en début de fonction. Après `_processEzoQueue()` qui peut bloquer ~900 ms, le handler met `_phSlopeQueriedMs = millis()` à un instant postérieur à `now` → underflow uint32 → ~4,3 milliards → toujours ≥ 86 400 000 → ré-enqueue immédiat → spam de query `Slope,?` ~1/s, monopolisation du mutex I²C, EZO ORP perturbé (logs « bus I²C dégradé » récurrents). Fix : recalcul de `now` après `_processEzoQueue()` + garde anti-underflow `nowAfterQueue >= _phSlopeQueriedMs`.
- **EZO ORP utilise `R` au lieu de `RT,<temp>`** (`c0f2962`) — `AtlasEzoSensor::readSingle()` envoyait indistinctement `RT,<temp>` aux deux modules Atlas. Sur l'EZO pH (0x63), cette commande compense la T° (Nernst) ET retourne la valeur compensée (statut 1 + payload). Sur l'EZO ORP (0x62), elle est ACCEPTÉE (statut 1 success) mais NE RETOURNE PAS de payload — l'ORP est potentiométrique direct sans compensation T°. Le firmware attendait un payload qui ne venait jamais → fail streak → bus I²C dégradé après 2 cycles → régulation ORP inhibée. Fix : différenciation par adresse I²C — `kEzoPhAddress` → `RT,<temp>`, `kEzoOrpAddress` → `R`. Validation empirique via `/debug/ezo_command` : `0x62 RT,25.0 → status=1 resp=""` vs `0x62 R → status=1 resp="-369.2"`.
- **Rate limit 30 → 120 req/min** (`6c79cfc`) — `kMaxRequestsPerMinute` passé de 30 à 120 (`src/constants.h`). Ancienne valeur trop basse pour navigation UI active normale (page /params ouverte + polls `/get-config` + `/data` + `/coredump/info` + clics → 30-45 req/min observés → warnings « Rate limit dépassé » fréquents). 120 req/min = 2 req/s moyenne reste une protection efficace contre brute-force auth (des années pour craquer un mot de passe 8 caractères) et DOS accidentel. WebSocket `/ws` non comptabilisé (connexion permanente).

### Fonctionnalités

- **Outil diagnostic EZO + endpoint factory reset** (`20e4a9b`) — 2 nouveaux endpoints HTTP (pas d'auth, cohérent avec les autres `/debug/*`) :
  - `POST /debug/ezo_command` — envoie une commande Atlas EZO arbitraire (1-30 chars) à n'importe quelle adresse I²C (`8..119` décimal = `0x08..0x77`) avec délai d'attente paramétrable (50-5000 ms). Retourne `{success, addr, cmd, status_code, status_label, response, raw_hex, delay_ms}`. Permet de diagnostiquer un module qui ne répond pas comme attendu, valider une réponse vide silencieuse, préparer un RMA Atlas avec preuves reproductibles.
  - `POST /debug/ezo_factory?addr=N` — restaure les paramètres usine d'un module Atlas EZO (calibration effacée, adresse I²C par défaut, baud rate UART par défaut, compensation T° reset). Le mode de communication (I²C vs UART) est PRÉSERVÉ — la commande ne touche pas le firmware EZO. Power-cycle ESP32 + recalibration recommandés après usage.
- **Carte UI « Diagnostic EZO »** dans Paramètres → Avancé (sous « Debug oscillation pH ») : sélecteur module (ORP 0x62 / pH 0x63), 10 boutons préprogrammés (`I`, `Status`, `R`, `Cal,?`, `Slope,?`, `L,?`, `L,1`, `L,0`, `Plock,?`, `Find`), champ commande personnalisée (max 30 chars) + délai paramétrable (50-5000 ms), affichage parsé (status code coloré vert/rouge selon code, réponse texte, bytes hex), historique scrollable des 30 dernières commandes (timestamp + cmd + status + réponse). Touche Entrée dans le champ perso → envoie.

### Documentation

- `docs/API.md` : nouvelle section « Outil diagnostic EZO » avec les 2 endpoints `/debug/ezo_command` et `/debug/ezo_factory`, exemples curl complets, table des status codes Atlas.
- `docs/features/page-settings.md` : nouvelle sous-section « Card Diagnostic EZO » sous le panel Avancé.
- `docs/subsystems/sensors.md` : section `readSingle()` mise à jour pour la différenciation pH/ORP, encart sur la garde 24 h `Slope,?` et l'anti-underflow `nowAfterQueue`.
- `docs/subsystems/history.md` : nouvelle sous-section « Détection de corruption LittleFS au boot » détaillant le test `/.fscheck` et la procédure de reformatage automatique.

### Notes

- Aucun ADR créé : les 5 commits sont des mitigations de bugs externes (LittleFS, firmware Atlas EZO), un outil de debug et un ajustement de seuil empirique. Pas de décision structurante avec alternative crédible à arbitrer.
- Build OK, validé en condition réelle avant publication.

---

## [2.1.0] - 2026-05-08

### Firmware
- **Pente sonde pH (feature-024)** — exposition des indicateurs d'usure de la sonde pH Atlas EZO via la commande `Slope,?`. Cache RAM `_phSlopeAcid/Base/Zero/QueriedMs` dans `Sensors`, getters publics `getPhSlopeAcid/Base/Zero()` + `getPhSlopeAgeMs()` + `enqueuePhSlopeQuery()`. Refresh automatique au boot, après chaque calibration EZO réussie (mid/low/clear) et toutes les 24 h (`kPhSlopeQueryIntervalMs = 86_400_000` ms). Dédoublonnage via flag `_phSlopeQueryPending` (anti-spam queue 4 slots). Invalidation cache à NaN après ≥ 2 échecs consécutifs (cohérent avec `_phCalCachedPoints`).
- **`AtlasEzoSensor::querySlope(PhSlopeInfo&)`** — parsing tolérant 2 ou 3 floats sur la réponse `?Slope,<acide>,<base>[,<zéro>]`. Mutex I²C tenu pendant toute la séquence (cmd + delay + read).
- **Feature strictement diagnostique** : aucun impact sur `canDose()` ni le PID. Validation `pool-chemistry` skip (passive).

### API HTTP / WebSocket
- **Nouvel endpoint** : `POST /debug/ph_slope_refresh` (sans auth, cohérent avec autres `/debug/*`) — force une re-query `Slope,?` immédiate. Réponse 200 `{success:true, queued:true}` ou 503 `{error:"queue full or already pending"}`.
- **Champs WS ajoutés à `sensor_data`** (4 champs, `null` si jamais lus / bus dégradé) : `phSlopeAcid` (% 1 décimale), `phSlopeBase` (% 1 décimale), `phSlopeZero` (mV 2 décimales), `phSlopeAgeMs` (entier ms ou `null`). Buffer WS bumpé à 1024 octets (+80).

### MQTT / Home Assistant
- **3 nouveaux topics** retain edge-triggered : `{base}/ph_slope_acid` (1 décimale), `{base}/ph_slope_base` (1 décimale), `{base}/ph_slope_zero` (2 décimales). Publication uniquement à la transition de la valeur arrondie — pas de spam.
- **3 sensors auto-discovery HA** : « Piscine pH Pente Acide » (`mdi:angle-acute`, unit `%`), « Piscine pH Pente Base » (`mdi:angle-obtuse`, unit `%`), « Piscine pH Décalage Zéro » (`mdi:sine-wave`, unit `mV`), tous avec `state_class: measurement`.
- Pas de `binary_sensor` « à remplacer » côté firmware — l'utilisateur peut le créer en automation HA selon ses propres seuils.

### Frontend
- **Chip d'état sonde pH** sur la carte « Lecture pH » (page `/ph`) — bouton focusable sous l'affichage pH 3 décimales. 5 variantes CSS (`chip--probe-good/warn/warn2/bad/unknown`) + classe `chip--probe-stale` (encadré jaune si âge > 36 h). Évaluation dans `data/app.js` (fonction `classifyPhProbe()`, constantes `PH_PROBE_*`) — seuils ajustables sans reflasher.
- **Modal détails** (`<dialog id="ph-probe-modal">`) au clic du chip : pente acide, pente base, décalage zéro, âge dernière vérif + bouton « Rafraîchir » → `POST /debug/ph_slope_refresh` (timeout 8 s, attente que `phSlopeAgeMs` redescende sous 60 s). Fallback non-cliquable si `<dialog>` non supporté (warning console).

### Fixes (correctifs code-reviewer feature-024)
- **Anti-spam HA** : trace brute `Slope,?` passée en `debug` (au lieu de `warning`) — la query auto 24 h faisait remonter du bruit dans le topic `{base}/logs` consommé par HA.
- **Cohérence WS** : `phSlopeAgeMs` désormais `null` si jamais lu (au lieu de `UINT32_MAX`), aligné avec les `phSlope*` nullables.
- **Icônes HA discriminantes** : `mdi:angle-acute` / `mdi:angle-obtuse` / `mdi:sine-wave` (au lieu de `mdi:chart-line` générique partagé).

### Documentation
- `docs/subsystems/sensors.md` : nouvelle section « Pente sonde pH — feature-024 » (méthode `querySlope()`, cache, refresh policy, invalidation), ajout `kPhSlopeQueryIntervalMs` au tableau des constantes, mention dans la liste des consommateurs WS / MQTT.
- `docs/MQTT.md` : nouvelle section « Topics et entités ajoutés en feature-024 » (3 topics + 3 sensors HA), ajout des 3 lignes dans le tableau topics capteurs.
- `docs/API.md` : nouvelle section « Endpoints ajoutés en feature-024 » (`POST /debug/ph_slope_refresh`), nouveaux champs WS dans le tableau payload `sensor_data`.
- `docs/features/page-ph.md` : nouvelle section « Chip d'état sonde » (placement, classification, modal, états stale, fallback `<dialog>`), ajout dans la table Actions et Interaction MQTT.
- Spec `specs/features/done/feature-024-pente-sonde-ph.md` (déplacée depuis `doing/`) avec section « Notes d'implémentation ».

### Build
- `pio run` SUCCESS, **RAM 18.0 %**, **Flash 99.8 %** (marge ~2.6 KB — point d'attention : prochaine feature potentiellement bloquée si pas de gain). `./build_fs.sh` SUCCESS, FS 1.1 MB.

### Risques résiduels
- Format de réponse `Slope,?` à confirmer empiriquement avec EZO réel — tolérance 2 ou 3 floats déjà en place pour les firmwares anciens.

---

## [2.0.0] - 2026-05-06

### Hardware
- **Migration PCB v2 — chaîne pH/ORP refondue sur Atlas Scientific EZO Embedded I²C (feature-021)**. Suppression matérielle de l'ADS1115 et de la sonde pH analogique. Modules EZO pH (`0x63`) et EZO ORP (`0x62`) sur le bus I²C partagé avec le DS3231. Voir [ADR-0014](docs/adr/0014-migration-atlas-ezo.md) — supersedes [ADR-0001](docs/adr/0001-capteurs-analogiques-ads1115.md).
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

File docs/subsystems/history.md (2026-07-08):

# Subsystem — `history`

- **Fichiers** : [`src/history.h`](../../src/history.h), [`src/history.cpp`](../../src/history.cpp)
- **Singleton** : `extern HistoryManager history;`
- **Partition** : `history` LittleFS **64 KB** (séparée de `spiffs`) — voir [`partitions.csv`](../../partitions.csv) et [ADR-0009](../adr/0009-partition-coredump.md).

## Rôle

Enregistre des snapshots des valeurs (pH, ORP, température, filtration active, dosing pH/ORP) toutes les 5 minutes. Consolide progressivement les données anciennes pour garder un historique utilisable sur **~82 jours** (7 jours de données horaires + 75 jours de données journalières) sans saturer la flash.

## Granularités

```cpp
enum Granularity : uint8_t {
  RAW    = 0,   // 5 min, gardés 6h    → 72 points max  (kMaxRawDataPoints)
  HOURLY = 1,   // moyenne 1h, gardée 7j → 168 points max (kMaxHourlyDataPoints)
  DAILY  = 2    // moyenne 1j, gardée 75j → 75 points max  (kMaxDailyDataPoints)
};
```

Voir [`constants.h:49`](../../src/constants.h:49) et [`history.h:30`](../../src/history.h:30).

## Cycle de vie d'un point

1. `recordDataPoint()` toutes les **5 min** (`RECORD_INTERVAL = 300000`) — ajout `RAW` dans `memoryBuffer`.
2. `consolidateData()` toutes les **5 min** (`SAVE_INTERVAL = 300000`) :
   - Points `RAW` plus anciens que 6 h → agrégés en moyenne horaire (`HOURLY`).
   - Points `HOURLY` plus anciens que 7 j → agrégés en moyenne journalière (`DAILY`).
   - Points `DAILY` plus anciens que 75 j → supprimés.
   - Appelle **`saveToFile()` en interne** à la fin du cycle de consolidation. Ne pas rappeler `saveToFile()` séparément depuis `update()` — c'est exactement le bug qui causait deux écritures flash + deux logs `Historique sauvegardé` toutes les 5 min.
3. Au boot : `loadFromFile()` restaure `memoryBuffer` depuis le fichier.

> Niveau de log : la trace `Consolidation terminée: N points` est en **DEBUG** (n'apparaît pas dans la persistance par défaut, niveau `INFO` minimum sur le fichier). Le marqueur antérieur `DEBUG: Début consolidation historique` a été supprimé.

## Math d'agrégation pure (`history_logic`)

- **Fichiers** : [`src/history_logic.h`](../../src/history_logic.h), [`src/history_logic.cpp`](../../src/history_logic.cpp)

Depuis **feature-041** (*characterization refactor*), la math **scalaire** d'agrégation est extraite de `history.cpp::consolidateData()` vers le module **pur** `history_logic` (pattern *Humble Object*, [ADR-0017](../adr/0017-logique-metier-pure-humble-object-testabilite.md)). Headers C uniquement (`<stdint.h>`/`<math.h>`), sans `<vector>`/`<map>`/Arduino/FreeRTOS — donc **testable en natif** sans libc++.

| Fonction | Rôle | Frontières / particularités |
|---|---|---|
| `bucketTimestamp(ts, bucketSeconds)` | Tronque un timestamp au début de son bucket (horaire/quotidien) : `(ts / bucketSeconds) * bucketSeconds` | `bucketSeconds == 0` → renvoie `ts` tel quel (garde anti-division par zéro) |
| `isOlderThan(now, ts, maxAgeSeconds)` | Prédicat d'ancienneté `(now - ts) > maxAgeSeconds` | Frontière **stricte** (`>`) : `age == maxAge` → `false`. Arithmétique `uint32`, wrap (`ts > now`) conservé tel quel |
| `finalizeMean(sum, count)` | Moyenne `sum/count` | `count == 0` → **`NaN`** (le point est ignoré par la coquille) |
| `isMajority(trueCount, total)` | Majorité stricte `trueCount > total/2` | Division **entière** : `2/4` → `false`, `3/4` → `true`, `3/5` → `true` |
| `anyTrue(count)` | « Au moins un » : `count > 0` | — |

Les deux passes de `consolidateData()` (raw → horaire, horaire → quotidien) **délèguent** à ces fonctions. *Characterization refactor* : la math reproduit **exactement** l'ancien comportement inline (frontières strictes, divisions entières, wrap `uint32`) — **aucun changement de comportement**. Ne pas « corriger » ces frontières.

> ⚠️ **Limite de testabilité** : seule la math scalaire est couverte en natif. Le **regroupement** par bucket (`std::map`/`std::vector`), l'accumulation des sommes/compteurs et la **persistance** (`saveToFile`) restent dans la coquille `consolidateData()` et **hors tests natifs** (contrainte libc++ absente de l'environnement natif). 25 tests Unity natifs ; `history_logic.cpp` couvert à **100 % des lignes**.

## Pré-NTP handling

Si un snapshot est pris **avant** que l'heure soit synchronisée (timestamp uptime < `kMinValidEpoch`), il est marqué via `_preNtpPending = true`. Dès la synchro NTP réussie, `_applyPreNtpCorrection(ntpEpoch, uptimeSec)` re-date les points en calculant `epoch = ntpEpoch − (uptimeSec − pointUptime)`.

## API publique

```cpp
void begin();
void update();
void recordDataPoint();
std::vector<DataPoint> getLastHours(int hours);
std::vector<DataPoint> getLastDay();
std::vector<DataPoint> getAllData();
bool importData(const std::vector<DataPoint>& dataPoints);
bool clearHistory();   // false si le mutex n'a pas pu être pris (historique occupé) — v2.11.1
```

## Endpoints HTTP

| Action | Endpoint | Auth |
|---|---|---|
| Récupérer l'historique | `GET /get-history?range={24h|7d|30d|3d|all}` | READ |
| Importer un CSV | `POST /history/import` (multipart) | CRITICAL |
| Purger l'historique | `POST /history/clear` | CRITICAL |

Voir [`web_routes_data.cpp:303`](../../src/web_routes_data.cpp:303). Colonnes CSV : `datetime, ph, orp, temperature, filtration, dosing, granularity`.

`POST /history/clear` répond **`503` « Historique occupé — réessayer »** si `clearHistory()` retourne `false` (mutex non obtenu dans le délai — voir section Concurrence).

## Concurrence

Un mutex FreeRTOS (`_mutex`, `SemaphoreHandle_t`) protège `memoryBuffer` contre les accès simultanés entre la tâche de loop et les handlers web asynchrones.

### Timeouts mutex bornés (feature-027, v2.11.1)

Les **6 prises de mutex** de `history.cpp` sont bornées par `kHistoryMutexTimeoutMs = 2000 ms` ([`constants.h`](../../src/constants.h)) — dimensionné sur le **pire détenteur légitime** : la consolidation + `saveToFile()` LittleFS (~1–1,5 s mesuré). Chaque timeout émet un `WARN` `[History] <site>: timeout mutex — opération sautée` **throttlé à 1/min/site** (`kMutexTimeoutWarnThrottleMs = 60000`, statique locale par site).

Politique d'échec par site :

| Site | Sur timeout |
|---|---|
| `update()` → `recordDataPoint()` | Point sauté, **`lastRecord` NON avancé** → retry naturel au tour de loop suivant (pas de trou de 5 min) |
| `update()` → `consolidateData()` | Consolidation sautée, **`lastSave` NON avancé** → retry naturel au tour suivant |
| `getLastHours()` | Vecteur vide (le client HTTP réessaiera). ⚠️ Un handler `async_tcp` peut désormais attendre **au plus 2 s** sur ce chemin — contre une attente *infinie* avant v2.11.1 (relevé en revue, amélioration nette) |
| `getAllData()` | Vecteur vide |
| `importData()` | `false` **avant toute modification** de `memoryBuffer` — la route teste le retour |
| `clearHistory()` | `false` **sans supprimer le fichier** (la RAM n'a pas été vidée → pas d'état incohérent) ; la route répond `503` |

Comportement nominal (mutex libre) strictement inchangé.

## Partition dédiée

La partition `history` (64 KB, offset `0x3E0000`) est **séparée** de `spiffs` pour que les updates OTA du filesystem (qui réécrivent `spiffs`) ne touchent pas à l'historique. Voir [ADR-0009](../adr/0009-partition-coredump.md).

**Budget de la partition (64 KB utiles ≈ 56 KB après réserves LittleFS) :**

| Fichier | Taille max |
|---|---|
| `history.bin` (données brutes + horaires + journalières) | ~24 KB |
| `system.log` (logs firmware persistés) | 16 KB |
| Fichier temporaire de rotation logs | 12 KB |
| **Total** | **~52 KB < 56 KB** |

### Protection au redimensionnement de partition

`HistoryManager::begin()` compare la taille réelle de la partition `history` (lue via l'API IDF) avec la taille stockée en NVS sous la clé `hist_meta/part_sz`. Si les tailles diffèrent (ou si la clé est absente = premier boot), la partition est effacée via `esp_partition_erase_range` avant montage LittleFS.

Cette protection évite un crash `IntegerDivideByZero` dans `lfs_alloc` lorsque LittleFS tente de monter un filesystem dont la géométrie ne correspond plus à la taille physique de la partition — situation qui se produit lors d'un redimensionnement flash (ex. migration ADR-0007 → ADR-0009).

> ⚠️ Le premier boot après un changement de table de partitions **efface l'historique**. C'est intentionnel et documenté dans [`docs/UPDATE_GUIDE.md`](../UPDATE_GUIDE.md).

### Détection de corruption LittleFS au boot (v2.1.1)

Le mécanisme précédent (vérification de taille) ne couvre **pas** les corruptions internes du filesystem (bit flips, écritures interrompues, métadonnées LittleFS incohérentes). LittleFS peut **monter sans erreur un FS corrompu** puis crasher en `IntegerDivideByZero` à la première écriture — symptôme observé sur PCB v1 après une longue inactivité ESP32 (boot loop sans message après le log « Partition historique dédiée montée »).

Depuis le commit `3c8b657` (v2.1.1), `HistoryManager::begin()` exécute, **après** un mount LittleFS réussi et **avant** tout autre accès (notamment `setPersistenceFs` qui déclenche le 1ᵉʳ printf vers le filesystem) :

1. **Test write** : ouverture en écriture du fichier témoin `/.fscheck`, écriture des 2 octets `"ok"`, fermeture.
2. **Test read** : ouverture en lecture, comparaison du contenu lu avec `"ok"`.
3. **Cleanup** : suppression de `/.fscheck`.

Si **toute** étape échoue (`open` retourne null, `print` retourne ≠ 2 octets, ou contenu lu ≠ `"ok"`), le firmware considère la partition corrompue :

- Log `warning` : `Partition history corrompue détectée — reformatage automatique`.
- Démontage LittleFS (`historyFs.end()`), effacement intégral via `esp_partition_erase_range(histPart, 0, histPart->size)`, remontage avec `formatOnFail=true`.
- Si le remontage post-erase échoue à son tour : log `error` + `historyEnabled = false` (le système boote, mais sans persistance d'historique).
- Sinon : log `info` : `Partition history reformatée et remontée`. L'historique persistant **est perdu** — c'est jugé acceptable face à un boot loop infini.

| Cas | Coût |
|-----|---|
| Nominal (FS sain) | 4 opérations FS + cleanup ≈ 10 ms au boot, ~500 B flash ajoutés |
| Corrompu | Erase 64 KB ≈ 100 ms + remount + reformatage LittleFS ≈ 300-500 ms total |

> Cette validation s'exécute **après** le test de redimensionnement de partition décrit ci-dessus. Les deux mécanismes sont indépendants : le premier détecte un changement de géométrie matérielle, le second détecte une corruption logique du filesystem monté avec succès.

## Cas limites

- **Partition pleine** : écriture impossible → log ERROR, `historyEnabled` peut être basculé à `false` manuellement depuis l'UI Avancé.
- **Migration d'une ancienne version** : `migrateLegacyHistory()` lit les fichiers au format précédent si `legacyHistoryPending = true`.
- **Boot sans heure** : les points sont enregistrés avec un timestamp uptime, corrigés à la synchro NTP.
- **Import d'un CSV malformé** : ligne rejetée individuellement, le reste est importé.

## Fichiers liés

- [`src/history.h`](../../src/history.h), [`src/history.cpp`](../../src/history.cpp)
- [`src/constants.h:49`](../../src/constants.h:49) — limites (`kMaxHourlyDataPoints = 168`)
- [`partitions.csv`](../../partitions.csv)
- [`src/history_logic.h`](../../src/history_logic.h), [`src/history_logic.cpp`](../../src/history_logic.cpp) — math d'agrégation pure
- [ADR-0009](../adr/0009-partition-coredump.md) — table de partitions courante
- [ADR-0007](../adr/0007-table-partitions-custom.md) — supersedé
- [ADR-0017](../adr/0017-logique-metier-pure-humble-object-testabilite.md) — logique métier pure / Humble Object

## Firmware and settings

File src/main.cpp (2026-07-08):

#include <Arduino.h>
#include <WiFi.h>
#include <ESPAsyncWebServer.h>
#include <DNSServer.h>
#include <LittleFS.h>
#include <ESPmDNS.h>
#include <esp_task_wdt.h>
#include <Preferences.h>
#include <nvs_flash.h>

#include "config.h"
#include "constants.h"
#include "logger.h"
#include "auth.h"
#include "sensors.h"
#include "pump_controller.h"
#include "filtration.h"
#include "lighting.h"
#include "mqtt_manager.h"
#include "web_server.h"
#include "web_routes_config.h"
#include "web_routes_control.h"
#include "history.h"
#include "version.h"
#include "rtc_manager.h"
#include "uart_transport.h"
#include "uart_protocol.h"

// Variables globales
DNSServer dns;
AsyncWebServer httpServer(kHttpServerPort);
unsigned long lastMqttPublish = 0;
wifi_mode_t currentWifiMode = WIFI_MODE_NULL;
bool ntpSyncedOnce = false;  // Flag pour éviter sync RTC multiple

// Déclaration des fonctions
bool setupWiFi();
void resetWiFiSettings();
void applyTimeConfig();
void checkSystemHealth();
void onNtpTimeSync();

void setup() {
  Serial.begin(115200);
  delay(kSerialInitDelayMs);

  systemLogger.begin();  // Initialise le mutex avant tout accès multi-core
  systemLogger.info("=== Démarrage ESP32 Pool Controller v" + String(FIRMWARE_VERSION) + " ===");
  systemLogger.info("Build: " + String(FIRMWARE_BUILD_DATE) + " " + String(FIRMWARE_BUILD_TIME));

  // Initialisation GPIO bouton factory reset et LED intégrée
  // PCB v2 (feature-019) : bouton factory reset sur GPIO35 (input-only,
  // sans pull-up interne possible) avec pull-up externe 10 kΩ vers 3V3 → actif bas.
  pinMode(kFactoryResetButtonPin, INPUT);
  pinMode(kBuiltinLedPin, OUTPUT);
  digitalWrite(kBuiltinLedPin, LOW);

  // Initialisation watchdog
  esp_task_wdt_init(kWatchdogTimeoutSec, true);
  esp_task_wdt_add(NULL);
  systemLogger.info("Watchdog activé (" + String(kWatchdogTimeoutSec) + "s)");

  // Montage système de fichiers
  if (!LittleFS.begin(false)) {
    systemLogger.critical("Échec montage LittleFS !");
  } else {
    systemLogger.info("LittleFS monté avec succès");
  }

  // Initialisation des mutex de protection concurrence
  initConfigMutexes();

  // Chargement configuration
  loadMqttConfig();
  loadProductConfig();
  // feature-053 : restaure l'état du Mode Boost (survit à un reboot dans la
  // journée ; expiré au chargement si minuit dépassé et heure valide).
  loadBoostState();

  // Initialisation UART écran (après chargement config pour respecter screenEnabled)
  if (authCfg.screenEnabled) {
    uartTransport.begin();
    systemLogger.info("Écran LVGL activé — UART2 initialisé");
  }

  // Initialisation authentification (après chargement config)
  authManager.setEnabled(authCfg.enabled);
  authManager.setPassword(authCfg.adminPassword);
  authManager.setApiToken(authCfg.apiToken);
  authManager.begin();

  // Sauvegarder le token généré si nécessaire
  if (authCfg.apiToken != authManager.getApiToken()) {
    authCfg.apiToken = authManager.getApiToken();
    saveMqttConfig();
  }

  // Initialisation des modules
  sensors.begin();  // Initialise aussi Wire (I2C)

  // Initialisation RTC DS1307 (après sensors.begin() qui initialise I2C)
  if (rtcManager.begin()) {
    // Si le RTC a une heure valide, l'appliquer au système
    // Cela donne une heure approximative avant que NTP ne soit disponible
    if (rtcManager.isTimeValid()) {
      rtcManager.applyToSystem();
    } else if (rtcManager.hasLostPower()) {
      systemLogger.warning("RTC: Heure non valide (batterie vide?), attente sync NTP ou réglage manuel");
    }
  }

  PumpController.begin();
  // feature-056 : en mode « alimenté par la filtration » (Powered), l'eau est
  // présumée présente dès le boot → armer le timer de stabilisation comme avant.
  if (mqttCfg.installMode == InstallMode::PoweredByFiltration) {
    PumpController.armStabilizationTimer();
  }
  filtration.begin();
  lighting.begin();
  history.begin();

  // Configuration WiFi
  bool wifiConnected = setupWiFi();

  if (wifiConnected) {
    // mDNS
    if (!MDNS.begin(kMdnsHostname)) {
      systemLogger.error("Échec démarrage mDNS");
    } else {
      MDNS.addService("http", "tcp", kMdnsHttpPort);
      systemLogger.info(String("mDNS: ") + kMdnsFullHost + " disponible");
    }

    // Initialisation MQTT
    mqttManager.begin();
    applyTimeConfig();

    // Connexion MQTT initiale gérée par mqttTask au 1er tour de taskLoop() — voir ADR-0011.
  }

  // Serveur Web (disponible en STA ou AP)
  webServer.begin(&httpServer, &dns);

  systemLogger.info("Initialisation terminée");
  esp_task_wdt_reset(); // Reset watchdog après init
}

void loop() {
  // Reset watchdog au début de chaque cycle
  esp_task_wdt_reset();

  unsigned long now = millis();
  currentWifiMode = WiFi.getMode();

  // Traiter les reconnexions WiFi asynchrones si nécessaire
  processWifiReconnectIfNeeded();

  // Mise à jour des gestionnaires
  webServer.update();
  mqttManager.update();              // No-op depuis ADR-0011 (mqttTask gère tout)
  mqttManager.drainCommandQueue();   // Applique les commandes HA reçues sous configMutex
  history.update();
  systemLogger.update();
  updateManualInject();
  if (authCfg.screenEnabled) uartTransport.update();

  // Lecture capteurs à chaque loop (les capteurs gèrent leur propre throttling interne)
  // DS18B20 : machine à états non-bloquante (request → wait → read) toutes les 2s
  // pH/ORP : lecture limitée à toutes les 5s en interne
  sensors.update();

  // Publication MQTT périodique
  if (mqttManager.isConnected() && now - lastMqttPublish >= kMqttPublishIntervalMs) {
    mqttManager.publishAllStates();
    lastMqttPublish = now;
  }

  // Contrôle filtration (s'exécute fréquemment pour précision)
  filtration.update();

  // Contrôle éclairage
  lighting.update();

  // Contrôle pompes dosage
  PumpController.update();

  // Détection appui long bouton factory reset (10s) en cours de fonctionnement.
  // PCB v2 (feature-019) : bouton actif bas, pull-up externe 10 kΩ vers 3V3.
  // GPIO35 est input-only sans pull-up interne possible.
  // Comportement utilisateur identique à PCB v1 : appui maintenu = factory reset.
  {
    static unsigned long buttonPressStart = 0;
    static bool lastPressed = false;
    static bool ledState = false;
    static unsigned long lastLedToggle = 0;
    bool pressed = (digitalRead(kFactoryResetButtonPin) == HIGH);

    if (pressed && !lastPressed) {
      // Début d'appui
      buttonPressStart = now;
      systemLogger.info("Bouton reset enfoncé - maintenir 10s pour factory reset");
    } else if (pressed && buttonPressStart > 0) {
      unsigned long held = now - buttonPressStart;

      // Faire clignoter la LED pendant l'appui
      if (now - lastLedToggle >= 200) {
        ledState = !ledState;
        digitalWrite(kBuiltinLedPin, ledState);
        lastLedToggle = now;
        esp_task_wdt_reset();
      }

      // Factory reset après 10s
      if (held >= kFactoryResetButtonHoldMs) {
        systemLogger.critical("=== FACTORY RESET CONFIRMÉ (appui 10s) ===");
        // Clignotement rapide de confirmation (5 fois)
        for (int i = 0; i < 10; i++) {
          digitalWrite(kBuiltinLedPin, i % 2);
          delay(150);
        }
        digitalWrite(kBuiltinLedPin, LOW);
        resetWiFiSettings();
        delay(500);
        mqttManager.shutdownForRestart();  // ADR-0011 : flush status=offline + stop mqttTask
        ESP.restart();
      }
    } else if (!pressed && lastPressed) {
      // Relâché avant 10s
      if (buttonPressStart > 0 && (now - buttonPressStart) < kFactoryResetButtonHoldMs) {
        systemLogger.info("Bouton relâché - factory reset annulé");
      }
      buttonPressStart = 0;
      digitalWrite(kBuiltinLedPin, LOW);
    }

    lastPressed = pressed;
  }

  // Vérification santé système périodique
  static unsigned long lastHealthCheck = 0;
  if (now - lastHealthCheck >= kHealthCheckIntervalMs) {
    checkSystemHealth();
    lastHealthCheck = now;
    esp_task_wdt_reset();
  }

  // Vérification sync NTP et mise à jour RTC
  if (!ntpSyncedOnce && mqttCfg.timeUseNtp && WiFi.isConnected()) {
    time_t nowTime;
    time(&nowTime);
    // Si l'heure est valide (après 2021), NTP a synchronisé
    if (nowTime > 1609459200) {
      onNtpTimeSync();
    }
  }

  // Sauvegarde périodique des volumes de produits (toutes les 60s si modifié)
  static unsigned long lastProductSave = 0;
  if (productConfigDirty && now - lastProductSave >= 60000UL) {
    saveProductConfig();
    mqttManager.publishProductState();
    lastProductSave = now;
  }

  // Publication diagnostic MQTT périodique
  static unsigned long lastDiagnosticPublish = 0;
  if (mqttManager.isConnected() && now - lastDiagnosticPublish >= kDiagnosticPublishIntervalMs) {
    mqttManager.publishDiagnostic();
    lastDiagnosticPublish = now;
  }

  // Petit délai pour ne pas monopoliser le CPU
  delay(kLoopDelayMs);
}

// Fonction utilitaire pour convertir le statut WiFi en string lisible
String getWifiStatusString(int status) {
  switch (status) {
    case WL_IDLE_STATUS: return "IDLE";
    case WL_NO_SSID_AVAIL: return "NO_SSID_AVAILABLE";
    case WL_SCAN_COMPLETED: return "SCAN_COMPLETED";
    case WL_CONNECTED: return "CONNECTED";
    case WL_CONNECT_FAILED: return "CONNECT_FAILED";
    case WL_CONNECTION_LOST: return "CONNECTION_LOST";
    case WL_DISCONNECTED: return "DISCONNECTED";
    default: return "UNKNOWN";
  }
}

bool setupWiFi() {
  WiFi.mode(WIFI_STA);
  // Désactiver le mode économie d'énergie : la radio reste allumée en permanence.
  // Sans ça, le mode par défaut WIFI_PS_MIN_MODEM fait dormir la radio entre les beacons DTIM,
  // ce qui cause une latence ping de 90-260ms au lieu de <10ms et des déconnexions MQTT toutes
  // les 1-2h (paquets queue côté AP qui finissent par déborder). L'ESP32 est alimenté en
  // permanence ici, le gain en autonomie n'a pas d'intérêt — la stabilité prime.
  WiFi.setSleep(false);

  // Logger les événements WiFi pour diagnostiquer les blackouts réseau (ping qui ne répond plus,
  // app injoignable, MQTT qui se reconnecte). Sans ces logs, impossible de savoir si la cause
  // est côté Wi-Fi (drop AP, RSSI, DHCP renew) ou côté firmware/broker.
  WiFi.onEvent([](WiFiEvent_t event, WiFiEventInfo_t info) {
    switch (event) {
      case ARDUINO_EVENT_WIFI_STA_DISCONNECTED: {
        uint8_t reason = info.wifi_sta_disconnected.reason;
        systemLogger.warning("WiFi déconnecté (reason=" + String(reason) + ")");
        break;
      }
      case ARDUINO_EVENT_WIFI_STA_CONNECTED:
        systemLogger.info("WiFi associé à l'AP");
        break;
      case ARDUINO_EVENT_WIFI_STA_GOT_IP:
        systemLogger.info("WiFi IP obtenue: " + WiFi.localIP().toString() +
                          " RSSI=" + String(WiFi.RSSI()) + "dBm");
        break;
      case ARDUINO_EVENT_WIFI_STA_LOST_IP:
        systemLogger.warning("WiFi IP perdue");
        break;
      default:
        break;
    }
  });

  currentWifiMode = WiFi.getMode();

  // Afficher les credentials WiFi stockés en NVS (pour debug)
  String storedSsid = WiFi.SSID();
  String storedPassword = WiFi.psk();
  //systemLogger.info("=== DEBUG WiFi Credentials ===");
  //systemLogger.info("SSID stocké: '" + storedSsid + "' (longueur: " + String(storedSsid.length()) + ")");
  //systemLogger.info("Password stocké: '" + storedPassword + "' (longueur: " + String(storedPassword.length()) + ")");
  //systemLogger.info("==============================");

  systemLogger.info("Tentative connexion WiFi...");

  // Connexion avec credentials sauvegardés (NVS)
  WiFi.begin();
  unsigned long start = millis();
  int lastStatus = -1;
  while (WiFi.status() != WL_CONNECTED && millis() - start < kWifiConnectTimeoutMs) {
    int currentStatus = WiFi.status();
    if (currentStatus != lastStatus) {
      // Afficher le code de statut WiFi
      systemLogger.info("Statut WiFi: " + String(currentStatus) + " (" + getWifiStatusString(currentStatus) + ")");
      lastStatus = currentStatus;
    }
    delay(250);
  }

  // Afficher le statut final
  int finalStatus = WiFi.status();
  systemLogger.info("Statut final: " + String(finalStatus) + " (" + getWifiStatusString(finalStatus) + ")");

  auto startApMode = [](bool keepSta) {
    // Toujours utiliser WIFI_AP_STA pour préserver les credentials NVS.
    // WIFI_AP seul peut effacer les credentials sur certaines versions IDF.
    (void)keepSta;
    WiFi.mode(WIFI_AP_STA);
    bool apStarted = WiFi.softAP("PoolControllerAP", authManager.getApPassword().c_str());
    if (apStarted) {
      systemLogger.info("AP démarré: PoolControllerAP");
      // Logger le mot de passe en clair uniquement si le wizard n'est pas encore complété
      // (premier boot, étiquette pas encore écrite). Après setup, utiliser GET /auth/ap-password.
      if (authManager.isFirstBootDetected()) {
        systemLogger.info("AP Password: " + authManager.getApPassword());
      } else {
        systemLogger.info("AP Password: [voir etiquette ou GET /auth/ap-password]");
      }
      systemLogger.info("IP AP: " + WiFi.softAPIP().toString());
      dns.start(53, "*", WiFi.softAPIP());
    } else {
      systemLogger.error("Impossible de démarrer le mode AP");
    }
  };

  if (WiFi.status() == WL_CONNECTED) {
    systemLogger.info("WiFi connecté: " + WiFi.SSID());
    systemLogger.info("IP: " + WiFi.localIP().toString());
    currentWifiMode = WiFi.getMode();

    // Réinitialiser le flag disableApOnBoot après une connexion réussie
    if (authCfg.disableApOnBoot) {
      systemLogger.info("Flag disableApOnBoot réinitialisé (connexion WiFi réussie)");
      authCfg.disableApOnBoot = false;
      saveMqttConfig();
    }

    // Activer le mode AP seulement si :
    // - forceWifiConfig est activé OU
    // - premier démarrage détecté ET
    // - le flag disableApOnBoot n'est PAS activé
    if ((authCfg.forceWifiConfig || authManager.isFirstBootDetected()) && !authCfg.disableApOnBoot) {
      systemLogger.warning("Mode AP activé (reset password ou premier démarrage): activation AP + STA");
      startApMode(true);
    } else if (authCfg.disableApOnBoot) {
      systemLogger.info("Mode AP désactivé (flag disableApOnBoot actif) - Mode STA uniquement");
    }
    return true;
  }

  // Échec de connexion WiFi
  // Ne pas démarrer l'AP si le flag disableApOnBoot est activé
  // (peut arriver si les credentials WiFi sont incorrects après configuration)
  if (authCfg.disableApOnBoot) {
    systemLogger.warning("Échec connexion WiFi mais disableApOnBoot actif - Mode STA sans AP");
    systemLogger.warning("L'ESP32 restera sans AP. Réinitialisez le mot de passe pour activer l'AP.");
    // Réinitialiser le flag après plusieurs échecs pour éviter un blocage permanent
    authCfg.disableApOnBoot = false;
    saveMqttConfig();
    return false;
  }

  systemLogger.error("Échec connexion WiFi, activation du mode AP");
  startApMode(false);
  currentWifiMode = WiFi.getMode();
  return false;
}

void resetWiFiSettings() {
  systemLogger.warning("Effacement complet de la partition NVS (factory reset)...");

  // Préserver le mot de passe AP : identifiant matériel unique, doit survivre au factory reset
  String savedApPassword = authCfg.apPassword;

  // Déconnecter le WiFi avant d'effacer
  WiFi.mode(WIFI_OFF);
  delay(100);

  // Effacer TOUTE la partition NVS - Équivalent à un factory reset
  // Cela efface TOUTES les données stockées : WiFi, Preferences, etc.
  esp_err_t err = nvs_flash_erase();
  if (err == ESP_OK) {
    systemLogger.info("Partition NVS effacée avec succès");

    // Réinitialiser la partition NVS
    err = nvs_flash_init();
    if (err == ESP_OK) {
      systemLogger.info("Partition NVS réinitialisée");

      // Restaurer le mot de passe AP immédiatement pour qu'il survive au redémarrage
      if (!savedApPassword.isEmpty()) {
        Preferences prefs;
        if (prefs.begin("poolctrl", false)) {
          prefs.putString("auth_ap_pwd", savedApPassword);
          prefs.end();
          systemLogger.info("Mot de passe AP restauré après factory reset");
        }
      }
    } else {
      systemLogger.error("Erreur réinitialisation NVS: " + String(err));
    }
  } else {
    systemLogger.error("Erreur effacement NVS: " + String(err));
  }

  systemLogger.info("Factory reset complet - Redémarrage nécessaire");
}

// Callback appelé quand NTP se synchronise
void onNtpTimeSync() {
  if (!ntpSyncedOnce) {
    ntpSyncedOnce = true;
    systemLogger.info("NTP synchronisé avec succès");

    // Mettre à jour le RTC avec l'heure NTP
    if (rtcManager.isAvailable()) {
      if (rtcManager.syncFromSystem()) {
        systemLogger.info("RTC mis à jour depuis NTP");
      }
    }
  }
}

void applyTimeConfig() {
  ensureTimezoneValid();
  applyTimezoneEnv();

  if (mqttCfg.timeUseNtp) {
    if (WiFi.isConnected()) {
      const TimezoneInfo* tz = currentTimezone();
      if (mqttCfg.ntpServer.length() == 0) {
        mqttCfg.ntpServer = "pool.ntp.org";
      }
      configTzTime(tz->posix, mqttCfg.ntpServer.c_str(), "time.nist.gov", "pool.ntp.org");
      systemLogger.info("Synchronisation NTP demandée: " + mqttCfg.ntpServer);

      // Reset le flag pour permettre une nouvelle sync RTC
      ntpSyncedOnce = false;
    } else {
      systemLogger.warning("NTP activé mais WiFi indisponible");
    }
  }
}
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

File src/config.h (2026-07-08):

#ifndef CONFIG_H
#define CONFIG_H

#include <Arduino.h>
#include <freertos/FreeRTOS.h>
#include <freertos/semphr.h>
#include "dosing_logic.h"  // feature-056 : enum InstallMode (logique pure partagée)

// ==== Configuration des canaux PWM pompes ====
// MOSFET IRLZ44N - PWM sur Gate, pins définis dans constants.h (PCB v2)
#define PUMP1_CHANNEL 0
#define PUMP2_CHANNEL 1
#define PUMP_PWM_FREQ 20000   // 20kHz PWM
#define PUMP_PWM_RES_BITS 8  // 8-bit resolution (0-255)

// ==== Constantes ====
constexpr float PH_DEADBAND = 0.01f;      // Zone morte réduite : 7.2 à 7.21 (±0.01)
constexpr float ORP_DEADBAND = 2.0f;      // Zone morte réduite : ±2mV
constexpr uint8_t MAX_PWM_DUTY = (1 << PUMP_PWM_RES_BITS) - 1;
constexpr uint8_t MIN_ACTIVE_DUTY = 80;

// ==== Home Assistant ====
const char* const HA_DEVICE_ID = "poolcontroller";
const char* const HA_DEVICE_NAME = "Pool Controller";
const char* const HA_DISCOVERY_PREFIX = "homeassistant";

// ==== Structures de configuration ====
struct MqttConfig {
  String server = "192.168.1.10";
  int port = 1883;
  String topic = "pool/sensors";
  String username = "";
  String password = "";
  bool enabled = false;
  float phTarget = 7.2f;
  float orpTarget = 650.0f;
  bool phEnabled = false;
  bool orpEnabled = false;
  int phPump = 1;
  int orpPump = 2;
  uint8_t pump1MaxDutyPct = 50;    // Puissance maximale pompe 1 en régulation (0-100 %)
  uint8_t pump2MaxDutyPct = 50;    // Puissance maximale pompe 2 en régulation (0-100 %)
  float pumpMaxFlowMlPerMin = 90.0f; // Débit maximal pompes (ml/min)
  int phInjectionLimitMinutes = 5;    // Max 5 min d'injection par fenêtre d'1h
  int orpInjectionLimitMinutes = 10;  // Max 10 min d'injection par fenêtre d'1h
  // feature-056 : mode d'installation (remplace regulationMode ET
  // filtrationCfg.enabled). Décrit le câblage réel et pilote la présence d'eau,
  // le relais filtration et l'horizon de répartition. Défaut = Managed (ancien
  // "pilote" + filtration gérée).
  InstallMode installMode = InstallMode::ManagedFiltration;
  int stabilizationDelayMin = 5;     // Délai de stabilisation avant dosage (minutes)
  String regulationSpeed = "normal"; // Vitesse de correction PID : "slow", "normal", "fast"
  String phCorrectionType = "ph_minus";  // "ph_minus" (acide) ou "ph_plus" (base)
  String phRegulationMode = "automatic"; // "automatic" / "scheduled" / "manual"
  int phDailyTargetMl = 0;               // Volume quotidien cible (mL) pour le mode programmée
  String orpRegulationMode = "automatic"; // "automatic" / "scheduled" / "manual"
  int orpDailyTargetMl = 0;               // Volume quotidien cible (mL) pour le mode Programmée ORP
  bool timeUseNtp = true;
  String ntpServer = "pool.ntp.org";
  String manualTimeIso = "";
  String timezoneId = "europe_paris";

  // feature-021 (Pass 4a) : calibration pH/ORP entièrement déléguée aux modules
  // Atlas EZO (commande Cal,? + cache _phCalCachedPoints / _orpCalCachedPoints
  // dans SensorManager). Aucun champ de calibration pH/ORP n'est plus persisté
  // en NVS côté ESP32. Les anciens champs phCalibrationDate/Temp,
  // orpCalibrationOffset/Slope/Date/Reference/Temp ont été supprimés.

  // Calibration Température DS18B20
  // Formule appliquée: Temp_final = Temp_brut + offset
  float tempCalibrationOffset = 0.0f; // Offset de calibration température (°C)
  String tempCalibrationDate = "";    // Date de calibration température (ISO 8601)
  bool temperatureEnabled = true;     // Fonction température activée/désactivée
};

struct FiltrationConfig {
  // feature-056 : le champ `enabled` a été absorbé par mqttCfg.installMode
  // (relais piloté ssi installMode == ManagedFiltration).
  String mode = "auto"; // auto, manual, off
  String start = "08:00";
  String end = "20:00";
  bool forceOn = false;  // Forçage ON temporaire (non persisté, remis à false au redémarrage)
  bool forceOff = false; // Forçage OFF temporaire (non persisté, remis à false au redémarrage)
};

struct LightingConfig {
  bool featureEnabled = true;          // Fonction éclairage activée/désactivée (masque l'UI)
  bool enabled = false;                // Éclairage ON/OFF manuel
  uint8_t brightness = 255;            // Luminosité PWM (0-255)
  bool scheduleEnabled = false;        // Programmation activée/désactivée
  String startTime = "20:00";          // Heure de début (HH:MM)
  String endTime = "23:00";            // Heure de fin (HH:MM)
};
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

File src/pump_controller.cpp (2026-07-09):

#include "pump_controller.h"
#include "config.h"
#include "constants.h"
#include "logger.h"
#include "sensors.h"
#include "filtration.h"
#include "uart_protocol.h"
#include "dosing_logic.h"
#include "schedule_logic.h"
#include <esp_task_wdt.h>
#include <time.h>

PumpControllerClass PumpController;

// pool-chemistry (feature-036) : verrou de complétude de la table énum→String FR
// du switch de canDose(). BurstPer15Min DOIT rester la dernière valeur de
// DoseRefusal ; si l'énum évolue, ce static_assert force la relecture du mapping.
static_assert(static_cast<int>(DoseRefusal::BurstPer15Min) == 14,
              "DoseRefusal modifié : mettre à jour le switch énum→String FR de canDose()");

// Définitions des membres statiques
bool PumpControllerClass::_dailyLoaded = false;
bool PumpControllerClass::_dailyCountersDirty = false;
unsigned long PumpControllerClass::_lastDailySaveMs = 0;
bool PumpControllerClass::_phWasActive = false;
bool PumpControllerClass::_orpWasActive = false;

PumpControllerClass::PumpControllerClass() {
  // Convention pool-chemistry : pumps[0] = pH, pumps[1] = ORP/chlore.
  pumps[0] = {kPumpPhPin,  PUMP1_CHANNEL};
  pumps[1] = {kPumpOrpPin, PUMP2_CHANNEL};

  // feature-025 (pool-chemistry) : coefficients par défaut "P temporisée pure".
  // pH garde les défauts du struct (Kp=8, Ki=0, Kd=0). ORP plus conservateur :
  // Kp=0.3 (l'ORP dépend du pH, de la T° et du stabilisant). Kd=0 IMPÉRATIF.
  orpPID.kp = 0.3f;
  orpPID.ki = 0.0f;
  orpPID.kd = 0.0f;
}

// Applique les paramètres PID selon la vitesse de régulation configurée.
//
// feature-025 (pool-chemistry, NON NÉGOCIABLE) : régulation "P temporisée pure".
//   - Ki = 0 et Kd = 0 IMPÉRATIFS quelle que soit la vitesse choisie.
//   - Seul Kp module la vitesse (slow / normal / fast).
//   - pH plus réactif (Kp 4..12), ORP plus conservateur (Kp 0.15..0.5) car l'ORP
//     dépend du pH, de la T° et du stabilisant.
// Les anciennes valeurs Ki≠0 / Kd≠0 sont volontairement supprimées : avec une mesure
// filtrée (médiane + EMA) et une pause mélange, un terme dérivé amplifierait le bruit
// résiduel et un terme intégral provoquerait un windup malgré l'anti-windup strict.
void PumpControllerClass::applyRegulationSpeed() {
  const String& speed = mqttCfg.regulationSpeed;
  if (speed == "slow") {
    phPID.kp  = 4.0f;
    orpPID.kp = 0.15f;
  } else if (speed == "fast") {
    phPID.kp  = 12.0f;
    orpPID.kp = 0.5f;
  } else {
    // "normal" (défaut)
    phPID.kp  = 8.0f;
    orpPID.kp = 0.3f;
  }
  // Ki/Kd toujours forcés à 0 (P temporisée pure — pool-chemistry feature-025).
  phPID.ki  = 0.0f;  phPID.kd  = 0.0f;
  orpPID.ki = 0.0f;  orpPID.kd = 0.0f;
  systemLogger.info("PID régulation (P temporisée): vitesse=" + speed +
    " Kp_pH=" + String(phPID.kp, 2) +
    " Kp_ORP=" + String(orpPID.kp, 2) +
    " Ki=0 Kd=0");
}

void PumpControllerClass::begin() {
  for (int i = 0; i < 2; ++i) {
    // MOSFET IRLZ44N: Configuration PWM sur Gate
    // Logic-level MOSFET compatible 3.3V ESP32.
    // Force OUTPUT en amont de ledcAttachPin : sur PCB v2, GPIO25 (DAC1/ADC2)
    // et GPIO33 (ADC1) restent muets si LEDC est attaché sans pinMode préalable.
    pinMode(pumps[i].pwmPin, OUTPUT);
    digitalWrite(pumps[i].pwmPin, LOW);
    ledcSetup(pumps[i].channel, PUMP_PWM_FREQ, PUMP_PWM_RES_BITS);
    ledcAttachPin(pumps[i].pwmPin, pumps[i].channel);
    ledcWrite(pumps[i].channel, 0);  // Pompe arrêtée au démarrage
    systemLogger.info("Pompe " + String(i + 1) + " : GPIO=" + String(pumps[i].pwmPin) +
                      " canal LEDC=" + String(pumps[i].channel));
  }
  applyRegulationSpeed();
  systemLogger.info("Contrôleur de pompes initialisé");
  systemLogger.info("Config pH: cible=" + String(mqttCfg.phTarget, 2) +
    " seuil=" + String(pumpProtection.phStartThreshold, 2) +
    " limite=" + String(mqttCfg.phInjectionLimitMinutes) + "min/h" +
    " max=" + String(safetyLimits.maxPhMlPerDay, 0) + "mL/j");
  systemLogger.info("Config ORP: cible=" + String(mqttCfg.orpTarget, 0) + "mV" +
    " seuil=" + String(pumpProtection.orpStartThreshold, 0) + "mV" +
    " limite=" + String(mqttCfg.orpInjectionLimitMinutes) + "min/h" +
    " max=" + String(safetyLimits.maxChlorineMlPerDay, 0) + "mL/j");
  systemLogger.info("Puissance: P1=" + String(mqttCfg.pump1MaxDutyPct) + "% P2=" + String(mqttCfg.pump2MaxDutyPct) + "%");
}

void PumpControllerClass::applyPumpDuty(int index, uint8_t duty) {
  duty = duty > MAX_PWM_DUTY ? MAX_PWM_DUTY : duty;
  if (pumpDuty[index] == duty) return;

  pumpDuty[index] = duty;

  // MOSFET IRLZ44N: Contrôle simple via PWM sur Gate
  // duty=0 → MOSFET OFF (pompe arrêtée)
  // duty>0 → MOSFET ON proportionnel (pompe tourne)
  ledcWrite(pumps[index].channel, duty);
}

void PumpControllerClass::refreshDosingState(DosingState& state, unsigned long now, bool manualActive) {
  if (state.windowStart == 0) {
    state.windowStart = now;
    state.lastTimestamp = now;
  }

  // Réinitialiser la fenêtre toutes les heures
  if (now - state.windowStart >= 3600000UL) {
    state.windowStart = now;
    state.usedMs = 0;
  }

  // Accumuler le temps d'injection.
  // feature-006 (condition pool-chemistry #2) : le budget horaire usedMs est
  // PARTAGÉ auto + manuel. `manualActive` couvre l'injection manuelle web, les
  // pompes test et l'UART (prédicat du safety tracking : manualMode && duty>0).
  // OR unique sur un seul point d'accumulation → PAS de double comptage possible
  // (une seule addition de delta par tour, quel que soit le mode actif).
  if (state.active || manualActive) {
    unsigned long delta = now - state.lastTimestamp;
    state.usedMs += delta;
    if (state.usedMs > 3600000UL) state.usedMs = 3600000UL;
  }

  state.lastTimestamp = now;
}


// COQUILLE (feature-036) : conserve le reset journalier de cyclesToday et le
// warning "Limite cycles atteinte" (effets de bord) ; délègue le verdict pur à
// shouldStartDosingPure().
bool PumpControllerClass::shouldStartDosing(float error, float startThreshold, DosingState& state, unsigned long now) {
  // Réinitialiser le compteur de cycles chaque jour
  if (state.cyclesDayStart == 0 || now - state.cyclesDayStart >= 86400000UL) {
    state.cyclesToday = 0;
    state.cyclesDayStart = now;
  }

  // Effet de bord conservé : warning edge-triggered quand la limite est atteinte.
  if (state.cyclesToday >= pumpProtection.maxCyclesPerDay) {
    static unsigned long lastWarning = 0;
    if (now - lastWarning > 3600000) {  // Log toutes les heures
      systemLogger.warning("Limite cycles atteinte: " + String(state.cyclesToday) + "/" + String(pumpProtection.maxCyclesPerDay));
      lastWarning = now;
    }
  }

  return shouldStartDosingPure(error, startThreshold, state.cyclesToday,
                               pumpProtection.maxCyclesPerDay);
}
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

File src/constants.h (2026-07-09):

#ifndef CONSTANTS_H
#define CONSTANTS_H

#include <stdint.h>

// =============================================================================
// GPIO PIN ASSIGNMENTS - PCB v2
// =============================================================================
// Mapping matériel pour le circuit imprimé v2. Voir feature-019 et
// docs/adr/0012-pcb-v2-gpio-mapping.md.
// Bascule unidirectionnelle : ce code n'est plus compatible avec le PCB v1.
//
// Note : kUart2RxPin (16) et kUart2TxPin (17) sont définis dans
// src/uart_transport.h — ne pas dupliquer ici.

// Pins actifs
constexpr uint8_t kBuiltinLedPin           = 2;   // LED bleue interne (status)
constexpr uint8_t kTempSensorPin           = 5;   // OneWire DS18B20 (eau + circuit, 2 sondes)
constexpr uint8_t kI2cSdaPin               = 21;  // I2C SDA — DS3231 + EZO pH + EZO ORP (default Arduino-ESP32)
constexpr uint8_t kI2cSclPin               = 22;  // I2C SCL — DS3231 + EZO pH + EZO ORP (default Arduino-ESP32)
constexpr uint8_t kPumpPhPin               = 25;  // Pompe doseuse pH (PWM via ledc)
constexpr uint8_t kFiltrationRelayPin      = 26;  // Relais filtration (actif haut)
constexpr uint8_t kLightingRelayPin        = 27;  // Relais éclairage (actif haut)
constexpr uint8_t kPumpOrpPin              = 33;  // Pompe doseuse ORP/chlore (PWM via ledc)
constexpr uint8_t kFactoryResetButtonPin   = 35;  // Bouton factory reset (input-only, pull-up externe 10kΩ — actif bas)

// Pins réservés feature-future — déclarés mais pas de pinMode() actif dans cette feature
constexpr uint8_t kRtcSqwPin               = 23;  // RTC DS3231 SQW (open-drain, INPUT_PULLUP attendu, future feature)
constexpr uint8_t kCtnAuxPin               = 32;  // CTN_AUX MOSFET 12V tableau (OUTPUT actif haut, future feature)
constexpr uint8_t kRtcIntPin               = 36;  // RTC DS3231 INT (input-only, pull-up externe 10kΩ, future feature)

// ============================================================================
// TIMING CONSTANTS - Intervalles et délais temporels
// ============================================================================

// Delays système
constexpr unsigned long kSerialInitDelayMs = 3000;        // Attente après Serial.begin()
constexpr unsigned long kLoopDelayMs = 10;                // Délai minimal entre cycles loop()
constexpr unsigned long kOtaYieldDelayMs = 1;             // Délai yield() pendant OTA

// Watchdog
constexpr unsigned long kWatchdogTimeoutSec = 30;         // Timeout watchdog en secondes

// Intervalles de mise à jour
constexpr unsigned long kMqttPublishIntervalMs = 10000;   // 10s - Publication état MQTT
constexpr unsigned long kHealthCheckIntervalMs = 60000;   // 60s - Vérification santé système
constexpr unsigned long kDiagnosticPublishIntervalMs = 300000; // 5min - Publication diagnostic MQTT
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

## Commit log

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2025-12-06 Amélioration de la calibration des sondes pH et ORP
    - Ajout de méthodes getRawOrp() et getRawPh() pour obtenir les valeurs brutes sans offset de calibration
    - Correction du bug de calibration ORP utilisant la valeur déjà calibrée au lieu de la valeur brute
    - Exposition des valeurs brutes (orp_raw, ph_raw) dans l'endpoint /data
    - Ajout de l'affichage de l'offset de calibration actuel dans l'interface web
    - Suppression des informations de debug de la page de calibration
    - Correction des retours à la ligne dans les modales de confirmation
    - Correction du problème de changement d'onglet lors de la calibration (ajout de type="button")
    - Chargement en arrière-plan des données capteurs pou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
    [sensors.cpp, sensors.h]
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2025-12-20 Intégration du capteur pH DFRobot SEN0161-V2 et améliorations de l'interface
    - Migration vers la librairie DFRobot_PH pour la gestion du capteur pH
    * Ajout de la dépendance DFRobot_PH dans platformio.ini
    * Simplification du système de calibration (2 points: pH 4.0 et 7.0)
    * Stockage automatique en EEPROM par la librairie
    - Corrections pour ESP32
    * Initialisation EEPROM avec EEPROM.begin(512) avant utilisation
    * Ajout de EEPROM.commit() après chaque calibration
    * Gestion correcte des valeurs NaN avec vérifications isnan()
    - Amélioration de l'interface web de calibration pH
    * Suppression de l'ancien système manuel avec saisie de valeurs
    * Nouveaux boutons simples: "Ca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
    [PoolController v1.0.csv, PoolController v1.0.kicad_pcb, PoolController v1.0.kicad_sch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]
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2025-12-22 Optimisations majeures ADS1115 et corrections critiques (v2025.12.5)
    ## Corrections critiques
    - **GAIN_ONE au lieu de GAIN_TWO**: Les modules pH/ORP sortent 0-3.3V
    - GAIN_TWO (±2.048V) saturait au-dessus de 2.048V (38% de perte)
    - GAIN_ONE (±4.096V) couvre toute la plage sans saturation
    - **computeVolts()**: Utilisation de la fonction bibliothèque au lieu de valeurs en dur
    - Adaptation automatique au gain configuré
    - Plus robuste et maintenable
    - **Calibration pH**: Corrections dans calibratePhNeutral() et calibratePhAcid()
    ## Optimisations performances
    - **Réduction échantillonnage**: 11→3 échantillons pH, 10→3 ORP
    - Temps de blocage réduit de ~1.4s à ~375ms
    - L'AD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
    [sensors.cpp]
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2025-12-23 Préparation pour publication GitHub
    Mise à jour complète de la documentation et nettoyage pour publication:
    Documentation:
    - Mise à jour README avec dernières fonctionnalités (PWM 20kHz, test pompes, ADS1115)
    - Ajout schéma de câblage détaillé avec MOSFETs IRLZ44N
    - Documentation calibration pH DFRobot et ORP via interface web
    - Ajout changelog version 2025.12.6
    - Ajout LICENSE MIT
    Configuration:
    - .gitignore: Exclusion des fichiers binaires (*.bin, *.elf)
    - .gitignore: Exclusion des backups KiCad automatiques
    - Nettoyage fichiers KiCad (suppression auto-save et anciens backups)
    Corrections:
    - src/mqtt_manager.cpp: Corrections mineures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
    [PoolController v1.0.kicad_sch]
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2025-12-23 Fix: Correction bug tracking sécurité dosage (ml injectés)
    Problème:
    - Le tracking des ml injectés utilisait lastTimestamp
    - lastTimestamp est réinitialisé à chaque cycle par refreshDosingState()
    - Delta toujours ≈0ms, rendant le suivi de sécurité inefficace
    - Limites journalières non respectées (risque surdosage)
    Solution:
    - Ajout de lastSafetyTimestamp dédié au tracking sécurité
    - Séparation tracking temps (lastTimestamp) vs sécurité (lastSafetyTimestamp)
    - Initialisation et reset appropriés
    - Logique appliquée pour pH et ORP
    Impact:
    - Tracking ml/jour maintenant précis et fiable
    - Protection contre le surdosage fonctionnelle
    - Sécurité renforcée
    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
    [pump_controller.cpp, pump_controller.h]
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2025-12-27 Fix: Correction formule getRawOrp() pour calibration 2 points
    La fonction getRawOrp() ne gérait pas correctement l'inverse de la
    calibration 2 points. Avec la formule calibrated = (raw × slope) + offset,
    l'inverse doit être raw = (calibrated - offset) / slope, et non pas
    simplement calibrated - offset.
    Ajout également d'une protection contre la division par zéro.
    [sensors.cpp]
2025-12-27 Perf: Appel sensors.update() à chaque loop pour réactivité DS18B20
    Le DS18B20 utilise un pattern asynchrone (request → wait → read) qui
    nécessite d'être appelé fréquemment pour fonctionner efficacement.
    En l'appelant seulement toutes les 10s, on perdait l'intérêt du mode
    non-bloquant et la réactivité était dégradée.
    Changements:
    - sensors.update() appelé à chaque loop (~10ms)
    - Le DS18B20 peut maintenant exécuter sa machine à états correctement
    - pH/ORP conservent leur throttling interne (5s)
    - Température se met à jour beaucoup plus rapidement
    - Suppression de la variable lastSensorRead devenue inutile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
    [main.cpp]
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2025-12-28 Refactor: Suppression des if(true) inutiles dans sensors.cpp
    - 6 occurrences de if(true) avec commentaires "PH_SENSOR_PIN/ORP_SENSOR_PIN est toujours défini"
    - Code smell qui nuit à la lisibilité
    - Vestiges d'une compilation conditionnelle abandonnée
    - Suppression des conditions if(true) { ... }
    - Suppression des blocs else { ... = NAN } devenus inutiles
    - Conservation des blocs { } pour scope des variables locales quand nécessaire
    - Correction de l'indentation
    Fichiers modifiés:
    - src/sensors.cpp:
    - Ligne 174: Lecture ORP - if(true) supprimé, bloc conservé
    - Ligne 258: else supprimé (orpValue = NAN)
    - Ligne 263: Lecture pH - if(true) supprimé, bloc con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
    [sensors.cpp]
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2025-12-28 Security: Renforcement authentification et corrections critiques
    Authentification et gestion des tokens:
    - Suppression interface Token API (seul MQTT utilisé pour Home Assistant)
    - Ajout vérification mot de passe actuel avant modification
    - Suppression transmission token par query parameter (fuite logs/historique)
    - Token uniquement via header X-Auth-Token
    - Correction boucle de connexion par implémentation pattern SPA:
    * Pages HTML publiques côté serveur
    * Vérification auth côté client (sessionStorage)
    * Routes API protégées par header X-Auth-Token
    - Ajout logs debug pour diagnostic authentification
    Configuration et CORS:
    - Correction fuite information route /get-config (do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
    [config.h, main.cpp]
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2025-12-28 Fix: Watchdog timeout lors lecture ADS1115 non connecté
    Problème: ESP32 rebootait après 30s avec watchdog timeout
    - Erreurs I2C répétées (Error 263) sur ADS1115 non connecté
    - 15 lectures × ~125ms par capteur pH/ORP = blocage prolongé
    - Timeouts I2C cumulés dépassaient 30s sans reset watchdog
    Solution: Ajout yield() dans boucle de lecture ADC
    - Permet au scheduler de tourner entre lectures
    - Reset implicite du watchdog via yield()
    - Pas d'impact sur précision (ADS1115 à 8 SPS déjà lent)
    Impact: ESP32 stable même avec sondes déconnectées
    [sensors.cpp]
2025-12-28 Fix: Correction timeout watchdog avec ADS1115 déconnecté
    Ajout d'un flag `adsAvailable` pour détecter si l'ADS1115 est présent
    au démarrage et désactiver complètement les lectures I2C si le capteur
    n'est pas détecté.
    Sans ce correctif, l'ESP32 redémarrait toutes les 30s via watchdog
    timeout car les tentatives de lecture I2C sur l'ADS1115 absent
    accumulaient des timeouts sans jamais céder le contrôle au système.
    Modifications:
    - sensors.h: Ajout du flag `adsAvailable`
    - sensors.cpp:
    * begin(): Définit adsAvailable selon ads.begin()
    * readRealSensors(): Skip complet des lectures ADC si !adsAvailable
    * calibratePhNeutral/Acid(): Vérification adsAvailable avant calibration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
    [sensors.cpp, sensors.h]
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2025-12-28 Feature: Mode AP conditionnel avec reset WiFi
    Modification du comportement WiFi pour activer le mode AP uniquement
    lors d'échec de connexion ou sur demande explicite via /reboot-ap.
    Problème résolu:
    - Le mode AP était toujours actif même avec connexion WiFi réussie
    - Le bouton "Redémarrer en mode AP" ne forçait pas vraiment le mode AP
    car les credentials WiFi restaient sauvegardés
    Solution implémentée:
    - main.cpp:
    * Nouvelle fonction resetWiFiSettings() pour effacer credentials
    * Utilise AsyncWiFiManager.resetSettings() de manière propre
    - web_routes_config.cpp:
    * Route /reboot-ap appelle resetWiFiSettings() avant redémarrage
    * Au prochain boot, autoConnect() active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
    [main.cpp]
2025-12-28 Fix: Effacement complet credentials WiFi via triple méthode
    Problème identifié:
    - WiFi.disconnect(true, true) seul n'effaçait pas les credentials
    stockés par AsyncWiFiManager dans Preferences
    - Résultat: erreur 0x300a (ESP_ERR_WIFI_SSID) au redémarrage, le
    mode AP ne s'activait pas
    Solution (triple approche pour garantir l'effacement):
    1. WiFi.disconnect(true, true) - efface credentials natifs ESP32
    2. Preferences.clear() sur namespace "wifi" - efface données
    AsyncWiFiManager
    3. WiFi.mode(WIFI_OFF) - désactive complètement le WiFi
    Comportement attendu:
    - /reboot-ap efface maintenant TOUS les credentials WiFi
    - Au redémarrage, AsyncWiFiManager.autoConnect() ne trouve aucun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
    [main.cpp]
2025-12-28 Fix: Affichage icône et accents dans portail WiFi AP
    Corrections apportées:
    1. Icône SVG: Passage de utf8 à base64 encoding pour garantir
    l'affichage correct dans tous les navigateurs
    2. Caractères accentués: Changement de charset="utf-8" vers
    charset="UTF-8" (majuscules, plus standard)
    3. Apostrophe: &apos; → \' pour "Point d'accès"
    4. Viewport: Ajout user-scalable=no pour meilleure UX mobile
    Encodage base64 du SVG:
    - L'encodage base64 est plus fiable que l'encodage UTF-8 URL
    - Fonctionne sur tous les navigateurs sans problème de décodage
    [main.cpp]
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2025-12-29 Fix: Centrage et responsive design du portail WiFi AP
    - Ajout flexbox pour centrage parfait sur tous écrans
    - Box-sizing global pour éviter débordements
    - Suppression scroll horizontal avec overflow-x hidden
    - Réduction padding form.portalap de 40px à 24px pour mobile
    - Centrage explicite du header (titre/sous-titre)
    - Correction largeur conteneurs pour affichage responsive
    Corrige l'affichage tronqué sur mobile et le décentrage des éléments.
    [main.cpp]
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2025-12-30 Feature: Partitions séparées + zones rouges graphique ORP
    Partitions:
    - Partition littlefs: 1344KB pour fichiers web
    - Partition history: 128KB séparée, préservée lors des OTA
    - Renommée partition "littlefs" en "spiffs" (requis par LittleFS.begin())
    Build & déploiement:
    - build_fs.sh: Script pour construire LittleFS avec taille correcte
    - deploy.sh: Script de déploiement automatisé (firmware, fs, all)
    - BUILD.md: Documentation complète du processus de build
    - PlatformIO ignore board_build.filesystem_size, d'où les scripts
    Graphiques:
    - ORP: Zones rouges au-dessus de 800mV et en-dessous de 600mV
    - ORP: Courbe sans remplissage (comme pH)
    - ORP: Lignes de référence à 600mV et 8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
    [partitions.csv]
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2025-12-30 feat: amélioration des graphiques, stockage historique et reset
    - échelles pH/ORP dynamiques avec zones de référence ajustées
    - reset mot de passe admin sur GPIO4 pour éviter le bootloader
    - historique sur partition dédiée avec filtrage plus sûr
    - documentation build/déploiement mise à jour
    [constants.h, main.cpp]
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2025-12-30 fix: historique sécurisé et heure UI
    - désactive l'historique si la partition est absente
    - corrige la sauvegarde/chargement en mode erreur
    - ajuste l'affichage horaire côté UI et applique la config filtration
    - allonge le délai d'init série
    [constants.h]
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2026-01-01 feat: gestion intelligente du mode AP et configuration WiFi
    Améliore la gestion du mode AP et ajoute une interface de configuration WiFi accessible depuis le login et l'application.
    **Gestion du mode AP améliorée :**
    - Active automatiquement le mode AP au premier démarrage
    - Active le mode AP après reset du mot de passe admin
    - Reconnexion WiFi automatique avec basculement en mode AP (3 tentatives)
    - Désactivation automatique du mode AP après connexion admin si WiFi connecté
    **Interface de configuration WiFi :**
    - Bouton "Configurer le Wi-Fi" affiché sur le login lors du premier démarrage ou reset password
    - Nouveau bouton dans les paramètres de l'application pour configurer le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
    [config.h, constants.h, main.cpp]
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2026-01-02 docs: documentation complète du bouton reset et schéma KiCad
    Documentation (QUICK_START.md):
    - Ajout section détaillée "Procédure de reset"
    - Documentation complète des effets du reset password
    - Ajout section "Après le reset" avec workflow complet
    - Précisions techniques sur le bouton (NO, pull-up interne)
    - Documentation activation automatique mode AP
    - Documentation bouton WiFi sur écran login
    - Documentation changement obligatoire du mot de passe
    Schéma KiCad (PoolController v1.0):
    - Ajout convertisseur ADS1115 (ADC 16 bits I2C)
    - Ajout bouton Reset (GPIO4 → GND, NO avec pull-up interne)
    - Mise à jour du schéma électronique
    Le bouton reset réinitialise:
    - Mot de passe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
    [PoolController v1.0.kicad_sch]
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2026-01-22 fix(ota): écriture directe dans partition SPIFFS pour mise à jour filesystem
    - Correction de la mise à jour OTA du filesystem qui ne fonctionnait pas
    - Utilisation de esp_partition_write() au lieu de Update API pour SPIFFS
    - Démontage de LittleFS avant écriture pour éviter les corruptions
    - Ajout de json_compat.h pour supprimer les warnings StaticJsonDocument deprecated
    - Remplacement de containsKey() deprecated par is<T>()
    [main.cpp]
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2026-01-22 Ameliore OTA et contraste accessibilite
    - stabilise filtration/eclairage si l'heure est indisponible
    - arrete les pompes pH/ORP pendant l'OTA puis reprise
    - renforce le contraste des textes/alertes dans l'UI
    [filtration.cpp, lighting.cpp, pump_controller.cpp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]
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2026-02-23 feat: ajoute contrôles de fonctionnalités et modes de régulation
    Modes de régulation pH/ORP:
    - Ajout du mode de régulation "continu" vs "piloté"
    - Piloté: dosage uniquement quand la filtration est active
    - Continu: dosage en permanence (alimentation liée à la filtration)
    - Ajout du type de correction pH: pH- (acide) ou pH+ (base)
    - pH- dose quand pH > cible
    - pH+ dose quand pH < cible
    Activation/désactivation des fonctionnalités:
    - Ajout de switches enable/disable pour chaque écran:
    - Filtration, Éclairage, Température, pH, ORP
    - Contenu masqué quand la fonction est désactivée
    - Backend: arrêt effectif des relais filtration/éclairage
    - Dashboard: widgets masqué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
    [config.h, filtration.cpp, lighting.cpp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]
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2026-03-05 fix: corrections hardware, UX et logique de contrôle
    - RTC: migration DS1307 → DS3231 (lostPower() au lieu de isrunning())
    - Capteurs: filtre valeur 85°C (reset EEPROM DS18B20), détection nombre de capteurs, utilise TEMP_SENSOR_PIN
    - Pompes: mode manuel actif même sans filtration (section Développement)
    - UI: efface les valeurs capteurs quand le contrôleur est hors ligne
    - deploy.sh: corrige python path (penv) et port USB
    - UPDATE_GUIDE.md: simplifié, commande esptool corrigée
    - API.md: authentification documentée (Basic Auth + X-Auth-Token), endpoints tous protégés
    - Supprime pre_production_check.sh (obsolète)
    [config.h, pump_controller.cpp, rtc_manager.cpp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]
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2026-03-05 fix(ph): corrige calibration et détection statut pH
    - Corrige la plage acide (2278→2210mV) et neutre (1683→1678mV) pour
    correspondre aux valeurs exactes de la lib DFRobot_PH
    - Corrige l'inversion des labels EEPROM (offset 0=neutre, offset 4=acide)
    - Ajoute écriture directe EEPROM en fallback si la lib rejette la tension
    hors plage (neutre: 1200-1900mV, acide: 1700-2500mV)
    - Ajoute flag _phCalibrated et méthode isPhCalibrated() dans SensorManager
    - Expose ph_cal_valid dans /config pour que l'UI affiche correctement le
    statut de calibration (était toujours "non calibré" faute de ce champ)
    [sensors.cpp, sensors.h]
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2026-03-06 feat(calibration): rafraîchissement 5s et valeurs brutes pendant calibration
    - Pendant la calibration pH/ORP, rafraîchissement des données toutes les 5s
    au lieu de 30s, via un interval dédié (startCalibrationRefresh)
    - Affichage de la tension brute (mV) pendant la calibration pH au lieu du pH
    corrigé (utilise le nouveau champ ph_voltage_mv de l'API /data)
    - Affichage de l'ORP brut (sans correction) pendant la calibration ORP
    - Suspension de l'enregistrement dans les graphiques pendant la calibration
    (pushPoint gardé par phCalibrationActive / orpCalibrationActive)
    - Suppression des mises à jour optimistes post-calibration (redondant avec
    le rechargement réel depuis l'ESP)
    - B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
    [sensors.cpp, sensors.h]
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2026-03-10 feat(filtration): refonte du mode Auto et amélioration de l'interface
    Mode Auto:
    - Suppression du mécanisme "premier cycle" (hasAutoReference/autoReferenceTemp)
    - Calcul immédiat du planning lors de l'enregistrement du mode Auto
    - Ajustement après 5 min de filtration pour corriger l'eau stagnante
    - Mode Auto désactivé si température non disponible (capteur ou feature)
    Interface Programmation:
    - Remplacement de l'auto-save par un bouton Sauvegarder (avec feedback)
    - Protection des modifications non sauvegardées contre le rechargement
    périodique de la config (flag filtrationDirty)
    - Contraste préservé sur les champs heure en mode Auto (classe is-computed)
    - Message d'aide mis à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
    [config.h, filtration.cpp]
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2026-03-19 feat: version 2.7.0 — interface améliorée et éclairage corrigé
    Interface :
    - Boutons Sauvegarder désactivés par défaut, activés dès qu'un champ est modifié
    - Sauvegarde manuelle ajoutée pour l'éclairage (cohérence avec les autres écrans)
    - Timestamps des logs convertis en HH:MM:SS (basé sur uptime_ms WS)
    - Messages d'injection pH/ORP centrés dans les widgets
    - Page À propos : versions des librairies mises à jour
    Éclairage :
    - État synchronisé via sensor_data WS (lighting.isOn() = état réel du relais)
    - Correction du revert d'état après clic (mise à jour optimiste de latestSensorData)
    - Correction de la programmation horaire bloquée par manualOverride persistant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
    [config.h, filtration.cpp, logger.cpp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]
2026-03-19 feat: version 2.8.0 — modes filtration, MQTT HA, badges capteurs
    - Filtration : refonte des modes (Programmation/Manuel/Désactivé), ajout du flag forceOff pour stopper la pompe même pendant la plage horaire, clear des overrides lors d'un changement de mode/horaires
    - MQTT : expose les commandes filtration et éclairage dans Home Assistant (switch, select), corrige le flickering du switch HA, ajoute "force" dans les options de mode
    - Tableau de bord : suppression de la zone d'alertes en haut, remplacement par des badges contextuels dans les widgets pH et ORP (hors plage, limite journalière atteinte)
    - Alertes pH/ORP basées sur les seuils configurés (ph_target ± 0.2, orp_target ± 150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
    [config.h, filtration.cpp, lighting.cpp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]
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2026-03-20 feat: suivi produits, délai stabilisation dosage, réinitialisation usine
    - Suivi volume pH et chlore : container, seuil alerte, reset bidon, switches UI
    - Délai de stabilisation avant injection (onglet Dosage) : bloque les pompes
    doseuses après démarrage filtration (mode piloté) ou boot ESP32 (mode continu)
    - Réinitialisation usine dans l'onglet Système : efface toute la NVS avec
    double confirmation, relance l'assistant de configuration
    - Heartbeat WebSocket 12 s : détection rapide de l'ESP32 hors tension
    - Reconnexion MQTT automatique dans update()
    - Badges capteurs pH/ORP dans les widgets du tableau de bord
    - Onglet Dosage (ex-Régulation) regroupant mode régulation + délai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
    [config.h, filtration.cpp, main.cpp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]
2026-03-21 fix(ui): corrige le clignotement du statut éclairage et renomme l'onglet
    - Fix: le statut éclairage changeait brièvement lors du démarrage/arrêt
    filtration car loadSensorData (HTTP /data) écrasait latestSensorData
    sans lighting_enabled, forçant le fallback sur config.lighting_enabled
    (état toggle, pas état relais). Supprime ce fallback erroné.
    - Renomme l'onglet Paramètres "Dosage" → "Régulation pH / ORP"
    - Ajuste la table de partitions : firmware 0x150000, SPIFFS 0x130000
    - Fixe la version plateforme espressif32 à 6.9.0
    - Ajoute reset OTA data dans deploy.sh pour forcer boot sur app0
    [partitions.csv]
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2026-03-21 fix(dosage): réinitialise le timer de stabilisation à l'arrêt de la filtration
    En mode piloté, le timer était armé au démarrage mais pas réinitialisé à
    l'arrêt, ce qui affichait un compte à rebours de stabilisation alors que
    la filtration était éteinte.
    [filtration.cpp, pump_controller.cpp, pump_controller.h]
2026-03-21 fix(dosage): corrige le compteur journalier de sécurité qui restait à 0
    dailyPhInjectedMl et dailyOrpInjectedMl étaient unsigned long, donc
    chaque petit incrément (~0.17 ml/cycle) était tronqué à 0 par le cast.
    La limite journalière n'était ainsi jamais atteinte malgré des volumes
    dépassant le seuil configuré.
    Correction : types passés en float, cast supprimé dans updateSafetyTracking.
    [config.h, pump_controller.cpp]
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2026-03-22 fix(dosage): corrige le calcul du débit effectif selon le duty réel
    L'ancien calcul (phFlow × actualDuty/requestedDuty) surestimait le débit
    car il supposait une proportionnalité depuis 0, sans tenir compte de
    MIN_ACTIVE_DUTY=20. La nouvelle fonction dutyToFlow() calcule le débit
    réel directement depuis le duty appliqué (inverse exact de flowToDuty).
    [pump_controller.cpp, pump_controller.h]
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2026-03-22 fix(config): remplace kPumpMaxFlowMlPerMin par 90.0f dans config.h
    config.h n'inclut pas constants.h, la constante n'était pas visible
    depuis les autres .cpp qui incluent config.h directement.
    [config.h]
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2026-03-26 fix(hardware): corrige le bouton factory reset et ajoute les fichiers hardware
    - Bouton factory reset : GPIO4 → GPIO32, actif haut (pull-down), logique inversée
    - Ajout détection appui bouton en cours de fonctionnement (log sans reset)
    - Ajout des fichiers hardware : Gerber PCB et modèles 3D boitier (STL)
    - Mise à jour documentation (GPIO, câblage, procédure reset)
    - Passe en version 1.0.1
    [esp32-pool-controller v3-Boitier.stl, esp32-pool-controller v3-Couvercle.stl]
2026-03-27 feat: factory reset runtime, nettoyage code et documentation
    - Factory reset : détection appui long 10s pendant fonctionnement (suppression détection au boot)
    - Suppression PH_SENSOR_PIN / ORP_SENSOR_PIN (vestiges ADC interne, remplacés par ADS1115 I2C)
    - Documentation : build_all.sh ajouté dans BUILD.md et UPDATE_GUIDE.md
    - Documentation : procédure factory reset mise à jour (fonctionnement runtime)
    - Documentation : section Matériel Requis remplacée par PCB (Gerber + schéma/PCB) et boîtier STL
    - Screenshots ajoutés (Schema.png, PCB.png et captures interface)
    [config.h, constants.h, main.cpp]
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
